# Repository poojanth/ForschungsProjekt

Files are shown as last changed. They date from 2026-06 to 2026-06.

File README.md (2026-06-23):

# ForschungsProjekt
KiCad PCB Design for an Implantable Optical Sensor System for Glioblastoma Cancer Patients

## Overview

This project focused on the design and optimization of a printed circuit board (PCB) for an implantable optical sensor system intended for biomedical research. The system concept is based on fluorescence detection for monitoring possible glioblastoma recurrence after tumor resection.

The implant concept consists of two main parts:

* **Sensor Unit** - responsible for fluorescence excitation and detection.
* **Control Unit** - responsible for power management, signal handling, and system control.

The aim of the project was to improve the electrical design, component selection, PCB layout, compactness, and feasibility of the optical implant system.

---

## My Contribution

* Researched requirements for implantable optical sensor systems
* Compared suitable electronic components for the device
* Investigated power management options for implantable medical devices
* Designed PCB layouts for the sensor unit and control unit using KiCad
* Considered compactness, signal integrity, power/ground planes, and routing rules
* Evaluated an alternative two-step placement approach for improved clinical feasibility

---

## Key Design Considerations

* Fluorescence excitation using UV/blue LEDs
* Fluorescence detection using photodiodes
* Compact PCB layout for implantable use
* Power-efficient component selection
* Separate power and ground planes for improved signal integrity
* MRI compatibility and biocompatibility considerations
* Sensor and control-unit separation for better placement flexibility

---

## Tools Used

* KiCad
* PCB schematic design
* PCB layout design
* Component datasheet analysis
* Literature research

---

## Skills Demonstrated

* PCB design
* Biomedical hardware design
* KiCad workflow
* Component selection
* Power management research
* Sensor system design
* Implantable medical device considerations
* Technical documentation

---

## Repository Structure

```text
.
├── KiCad_Project/
│   ├── project_file.kicad_pro
│   ├── schematic.kicad_sch
│   └── pcb_layout.kicad_pcb
│
├── Docs/
│   ├── schematic.pdf
│   ├── pcb_layout_images/
│   └── 3d_pcb_views/
│
├── README.md
└── .gitignore
```

---

## Project Status

This project represents a research and design-stage PCB development work. The PCB layout and component selection were completed as part of the research project. Experimental validation and hardware testing were identified as future work.

---

## Confidentiality Note

This repository contains only a non-confidential project overview and selected design documentation. Sensitive institutional material, unpublished restricted details, and confidential research data are not included.

---

## Author

**Poojan Thakar**
M.Sc. Medical Systems Engineering
Otto von Guericke University Magdeburg

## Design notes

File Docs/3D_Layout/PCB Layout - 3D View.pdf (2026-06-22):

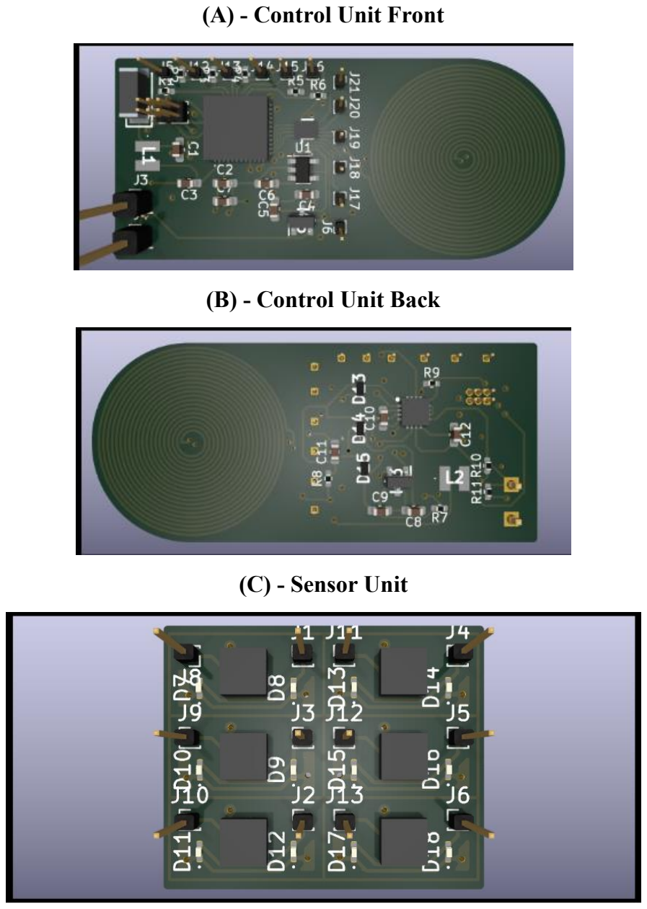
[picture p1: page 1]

(A) - Control Unit Front
(B) - Control Unit Back
(C) - Sensor Unit

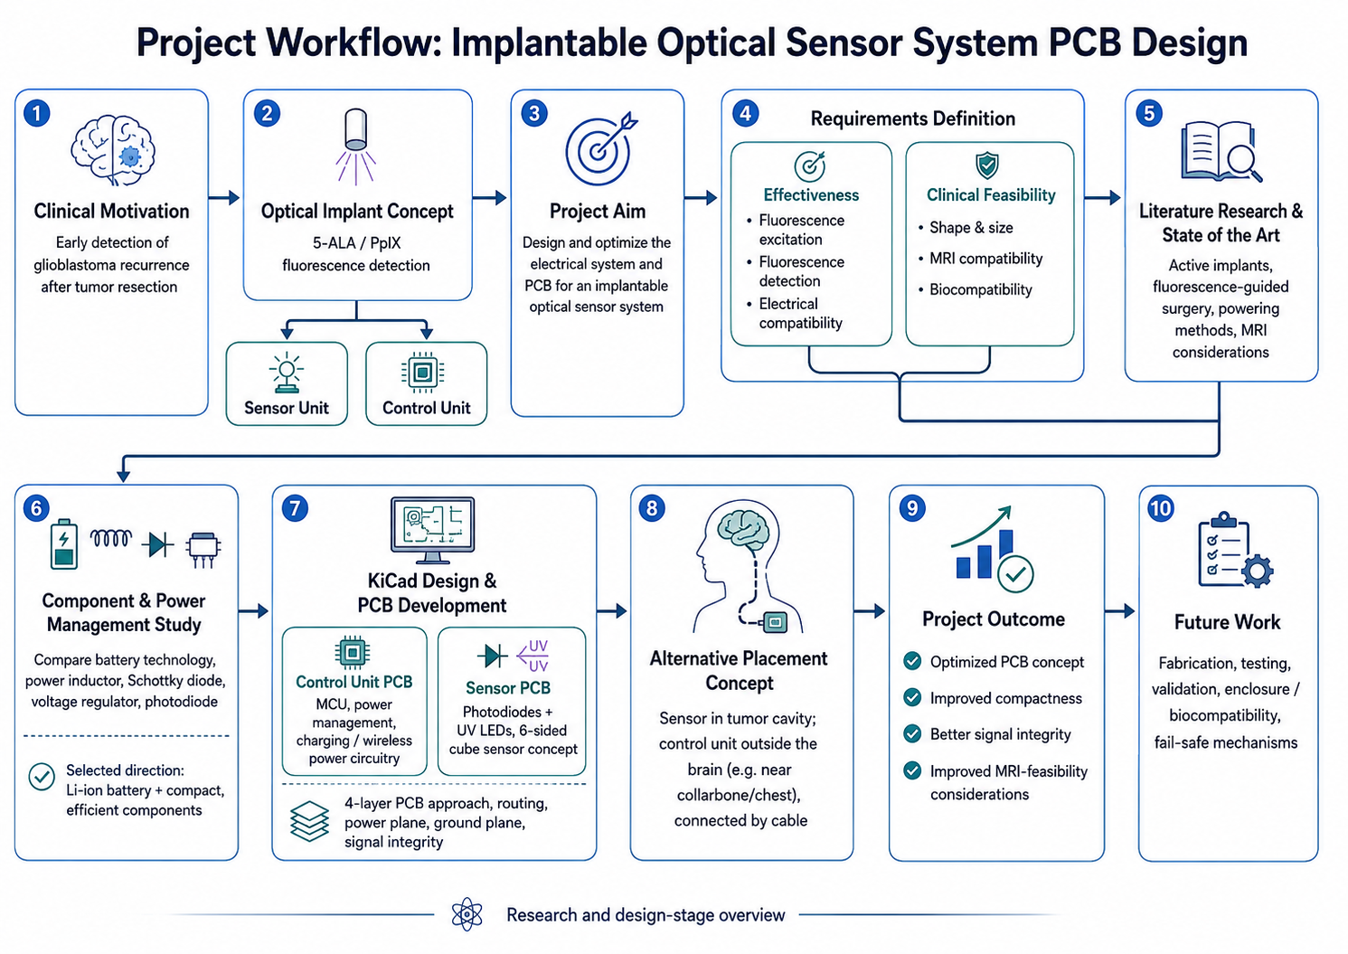
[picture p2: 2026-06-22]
Docs/Workflow/Research Project - Workflow.png

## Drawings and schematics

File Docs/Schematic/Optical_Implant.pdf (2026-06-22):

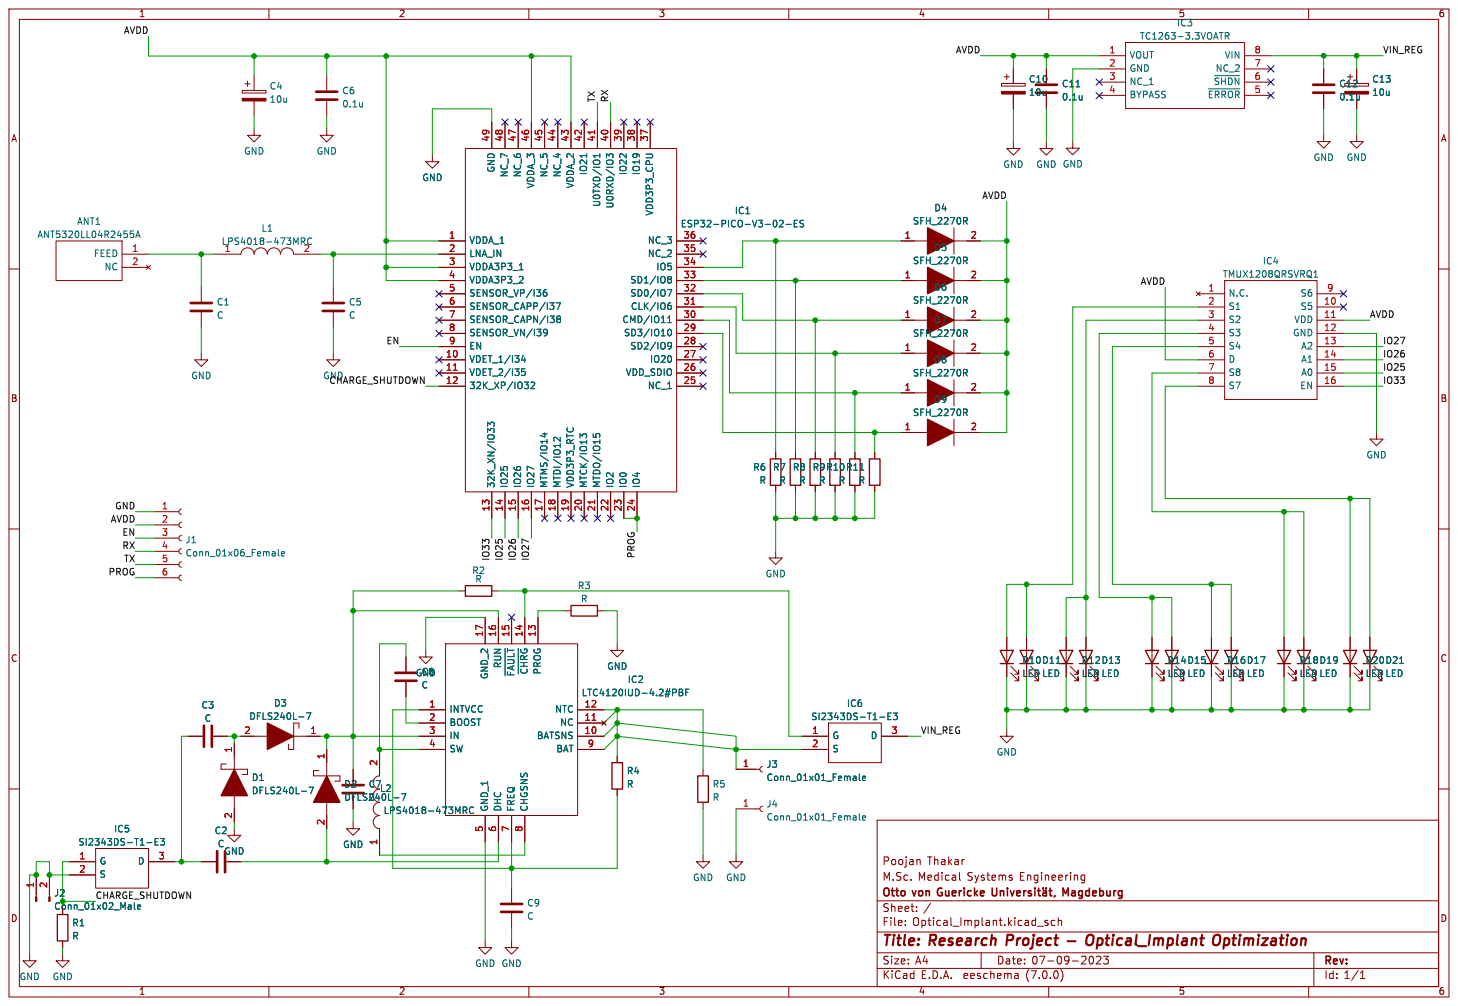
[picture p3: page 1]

Id: 1/1 Title: Research Project - Optical_Implant Optimization

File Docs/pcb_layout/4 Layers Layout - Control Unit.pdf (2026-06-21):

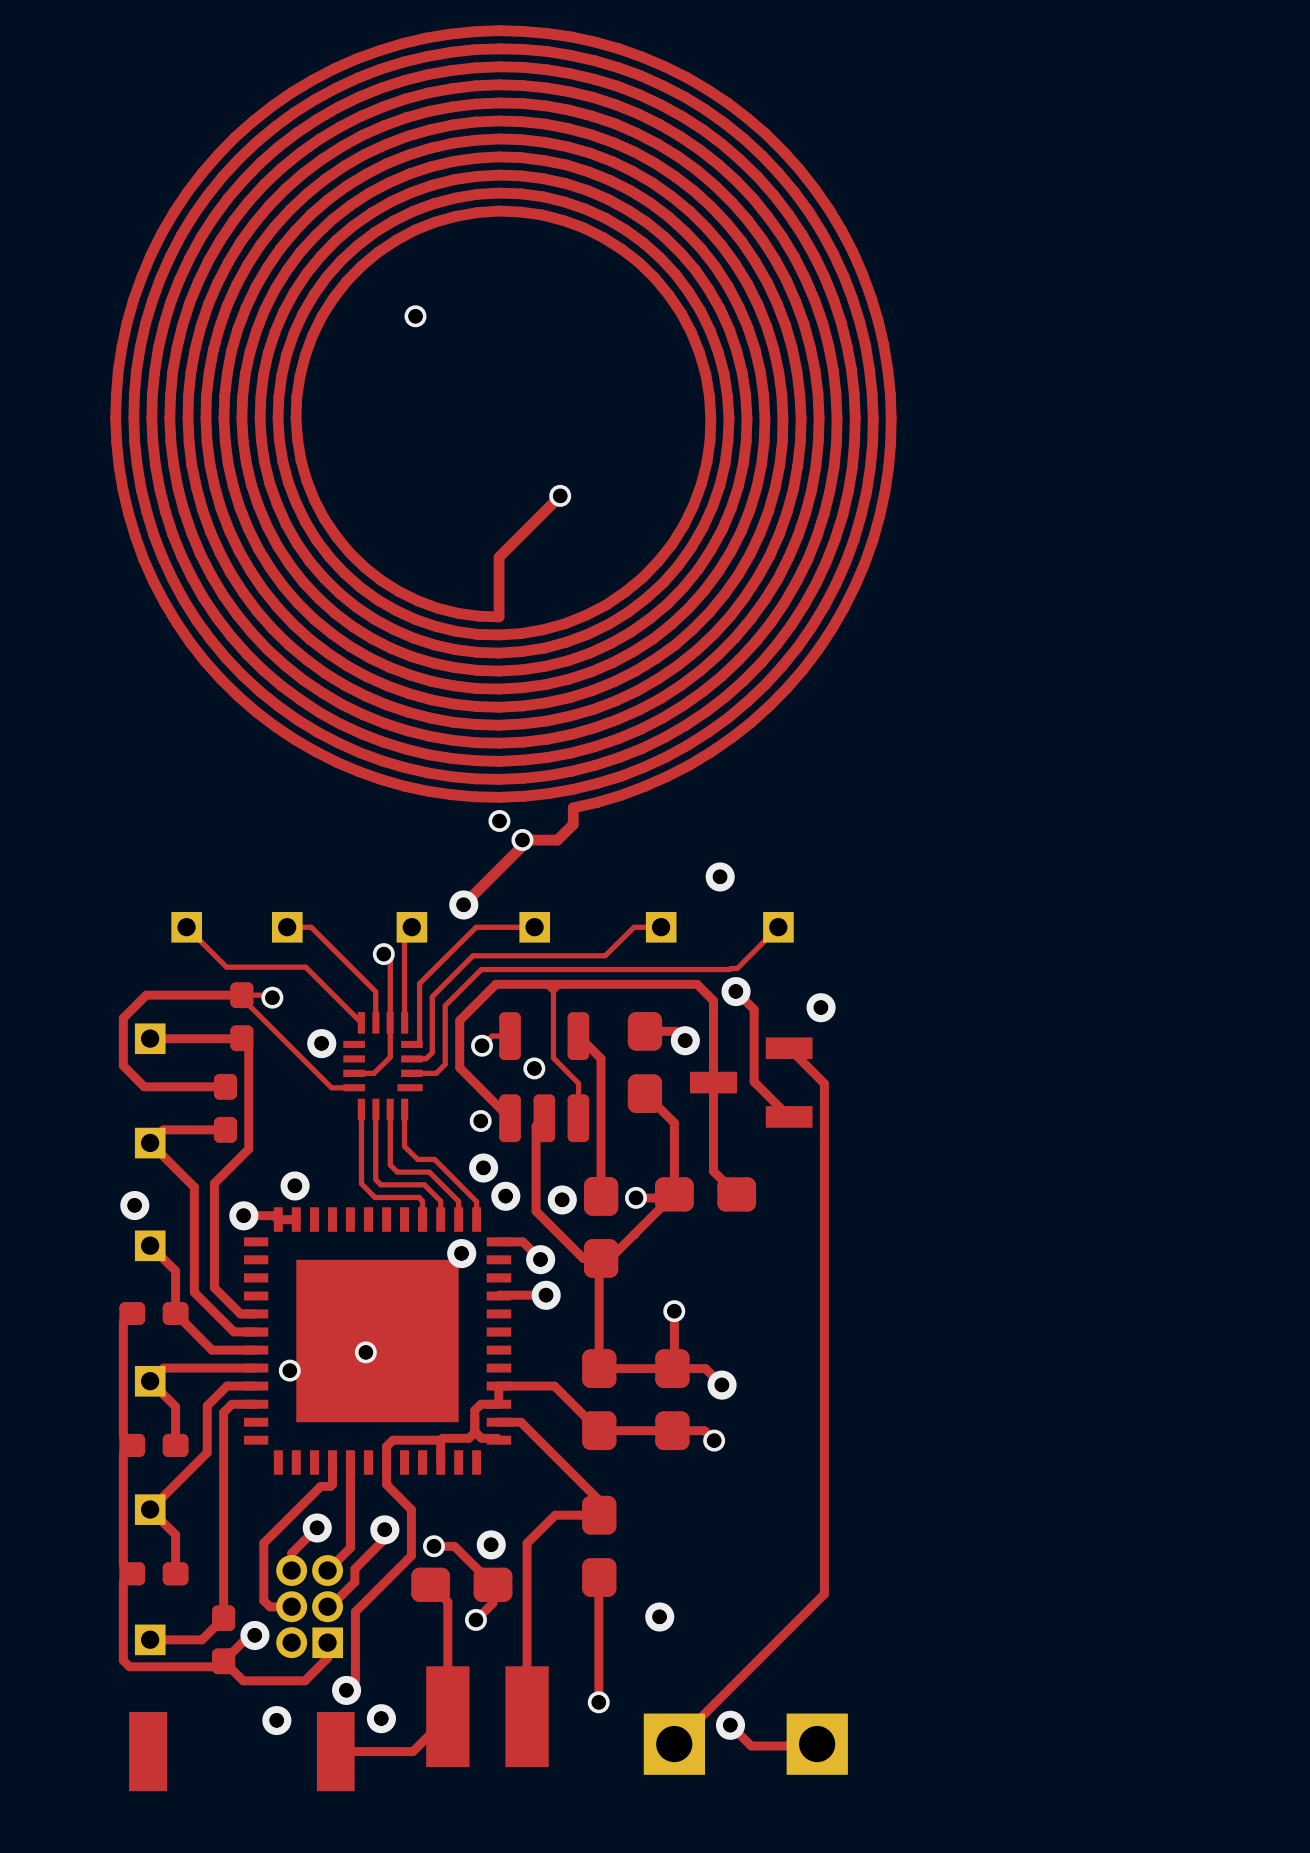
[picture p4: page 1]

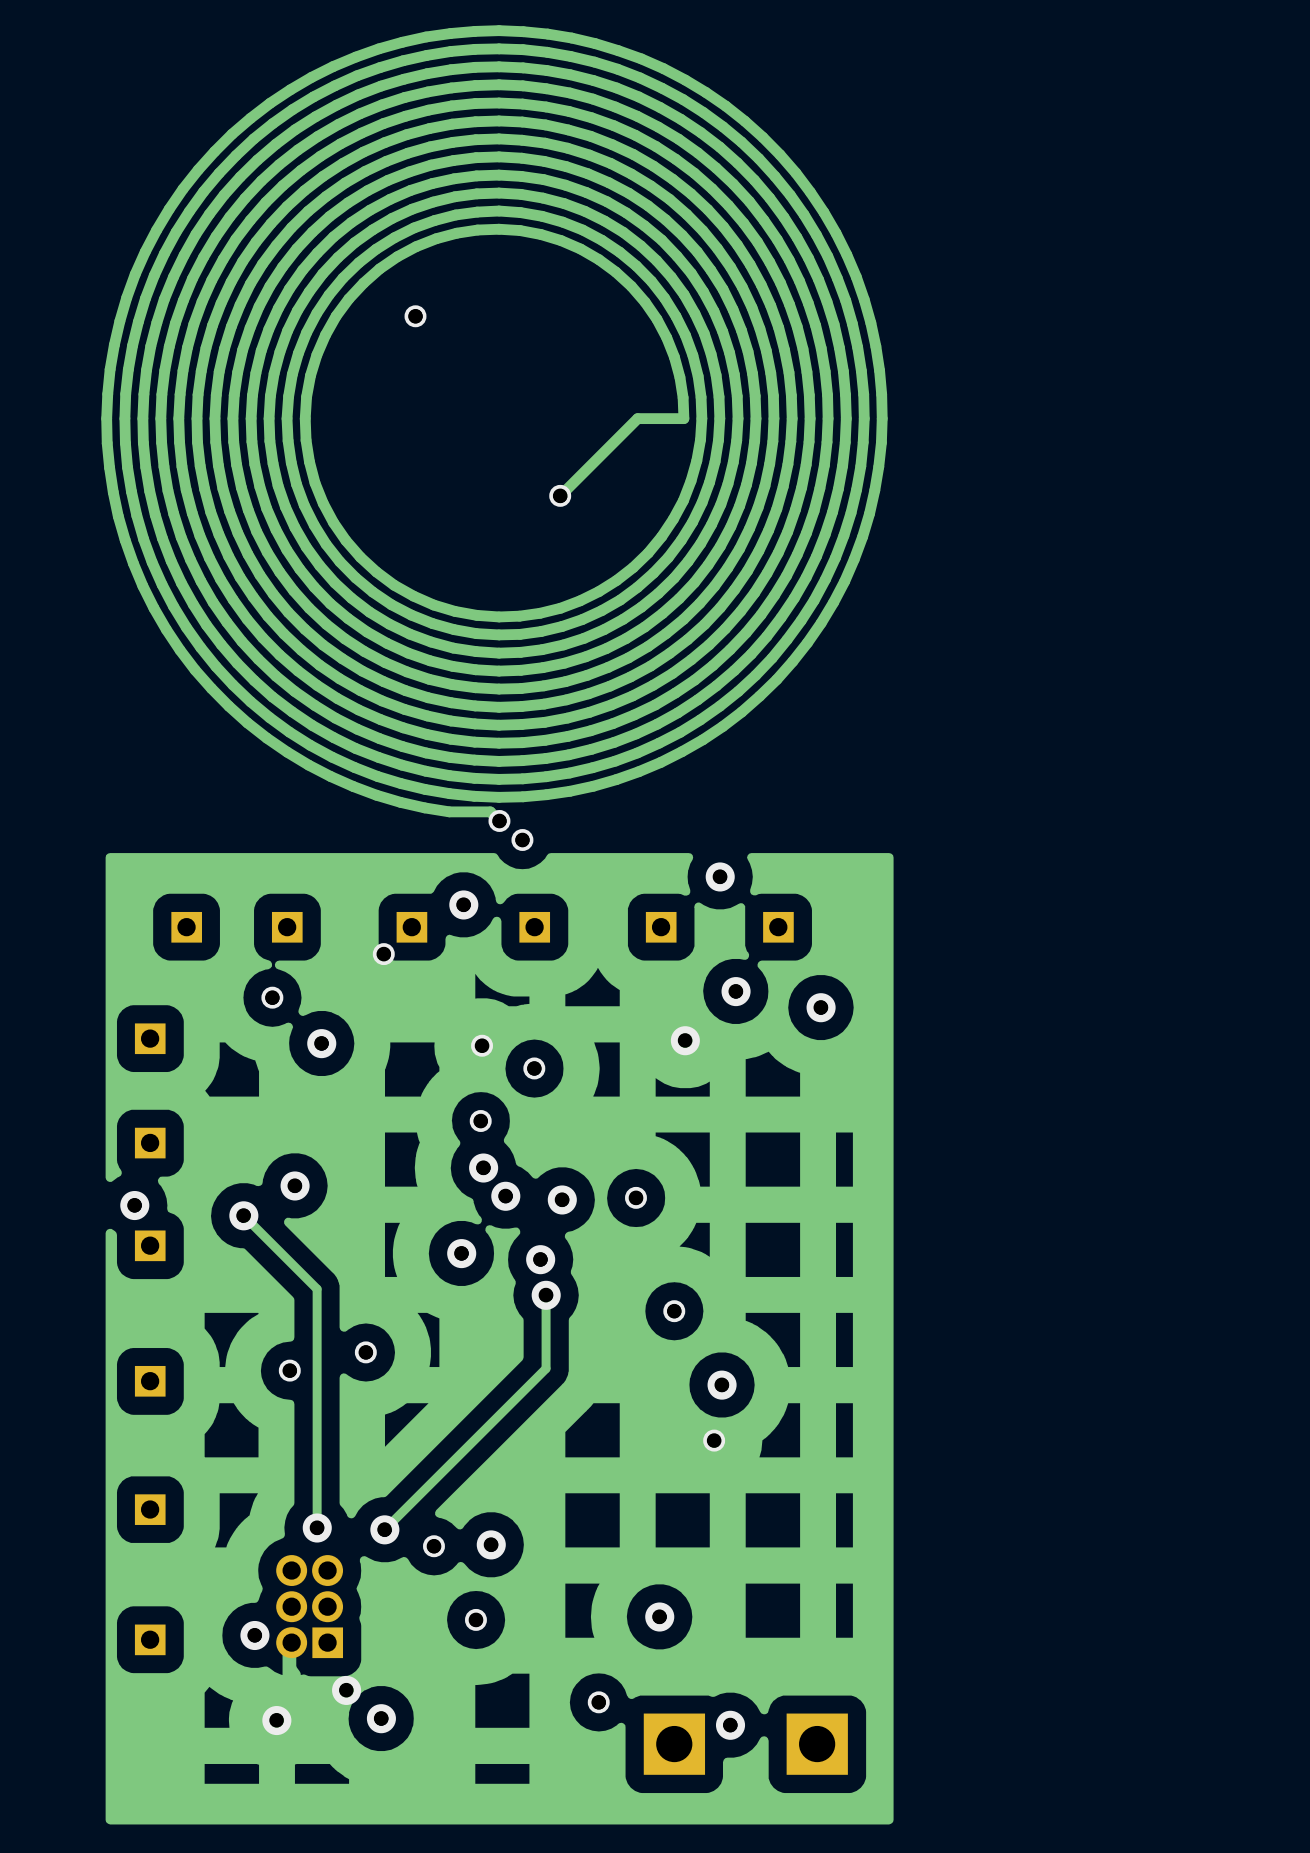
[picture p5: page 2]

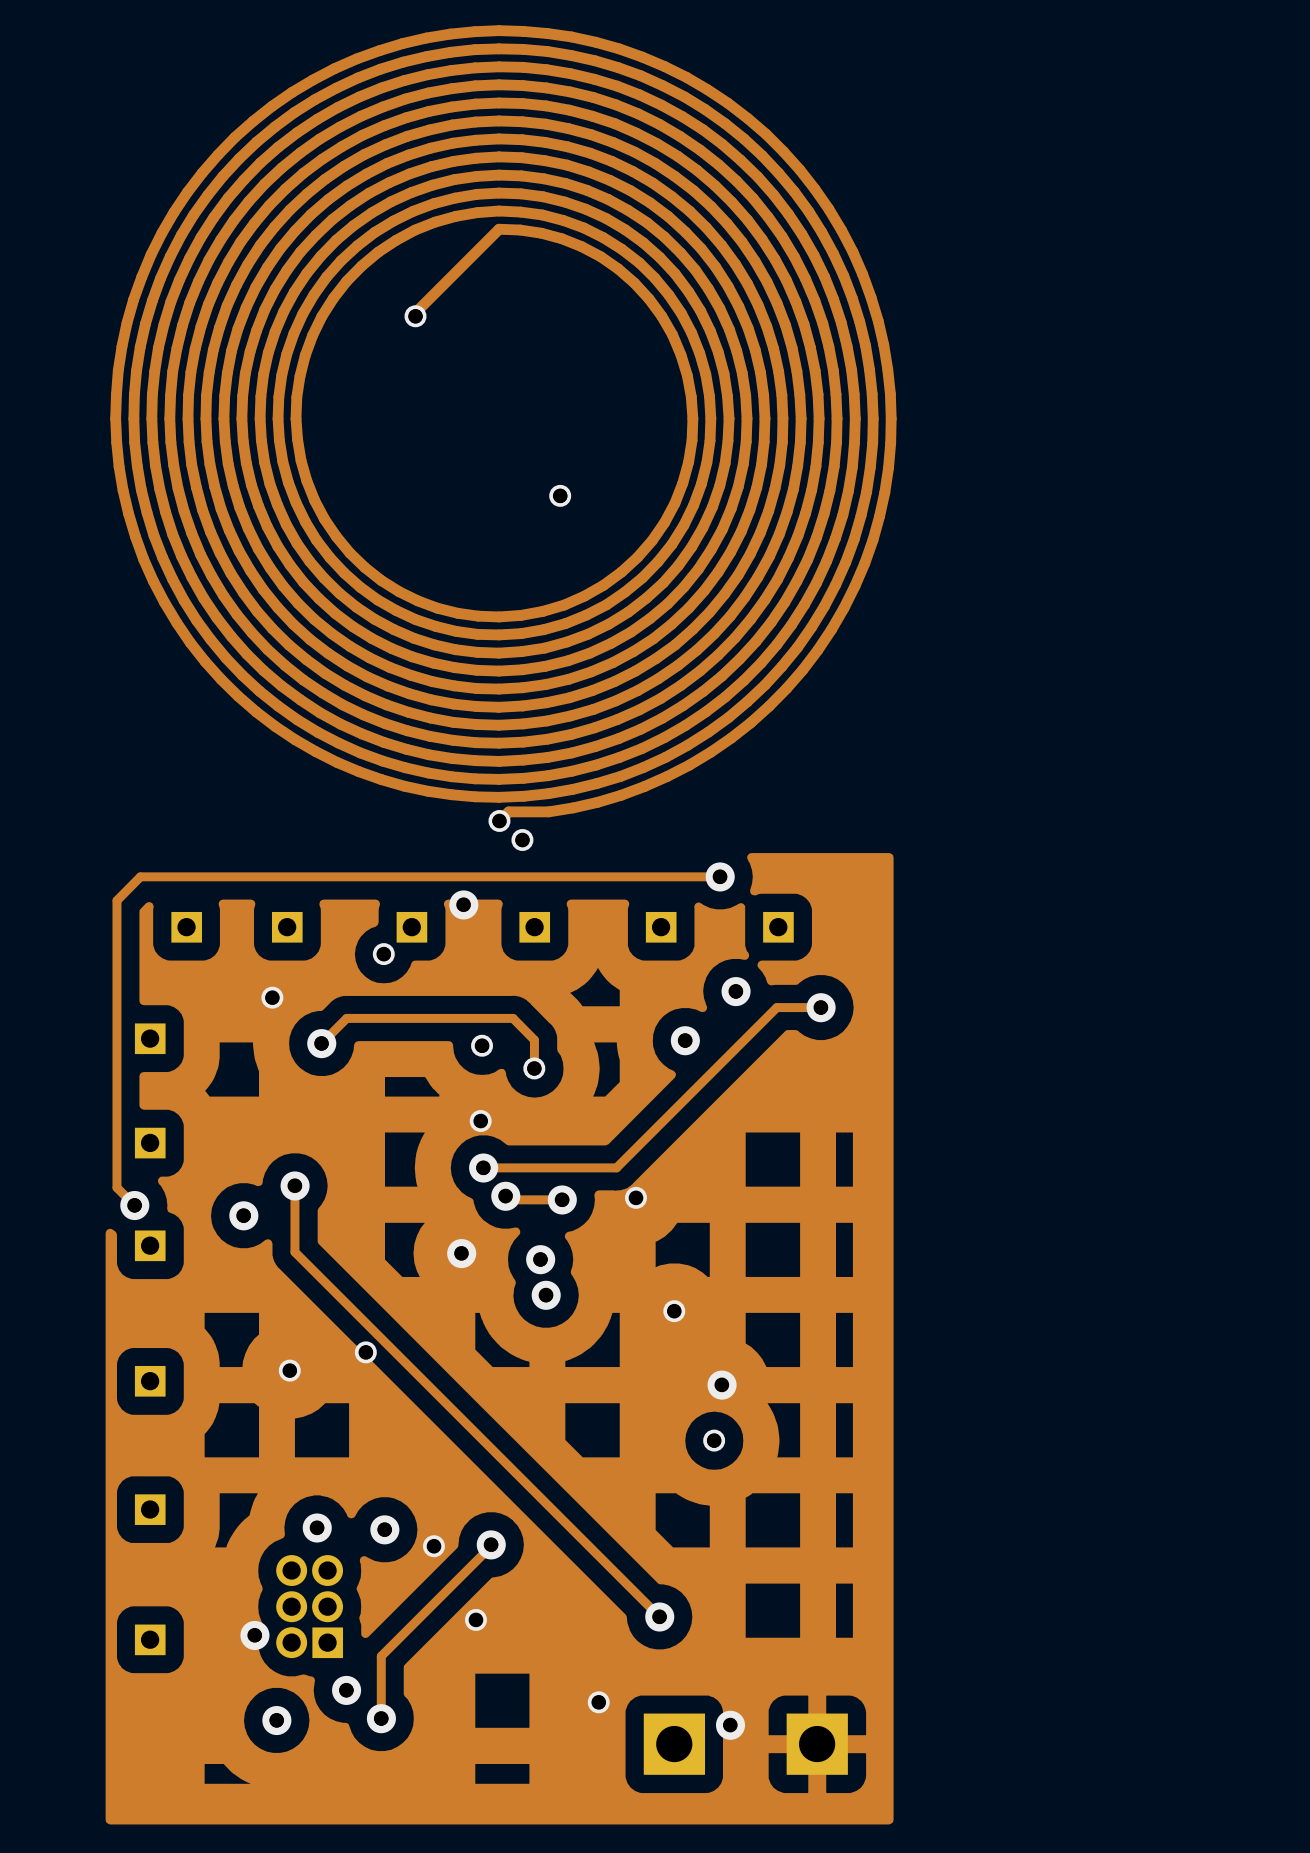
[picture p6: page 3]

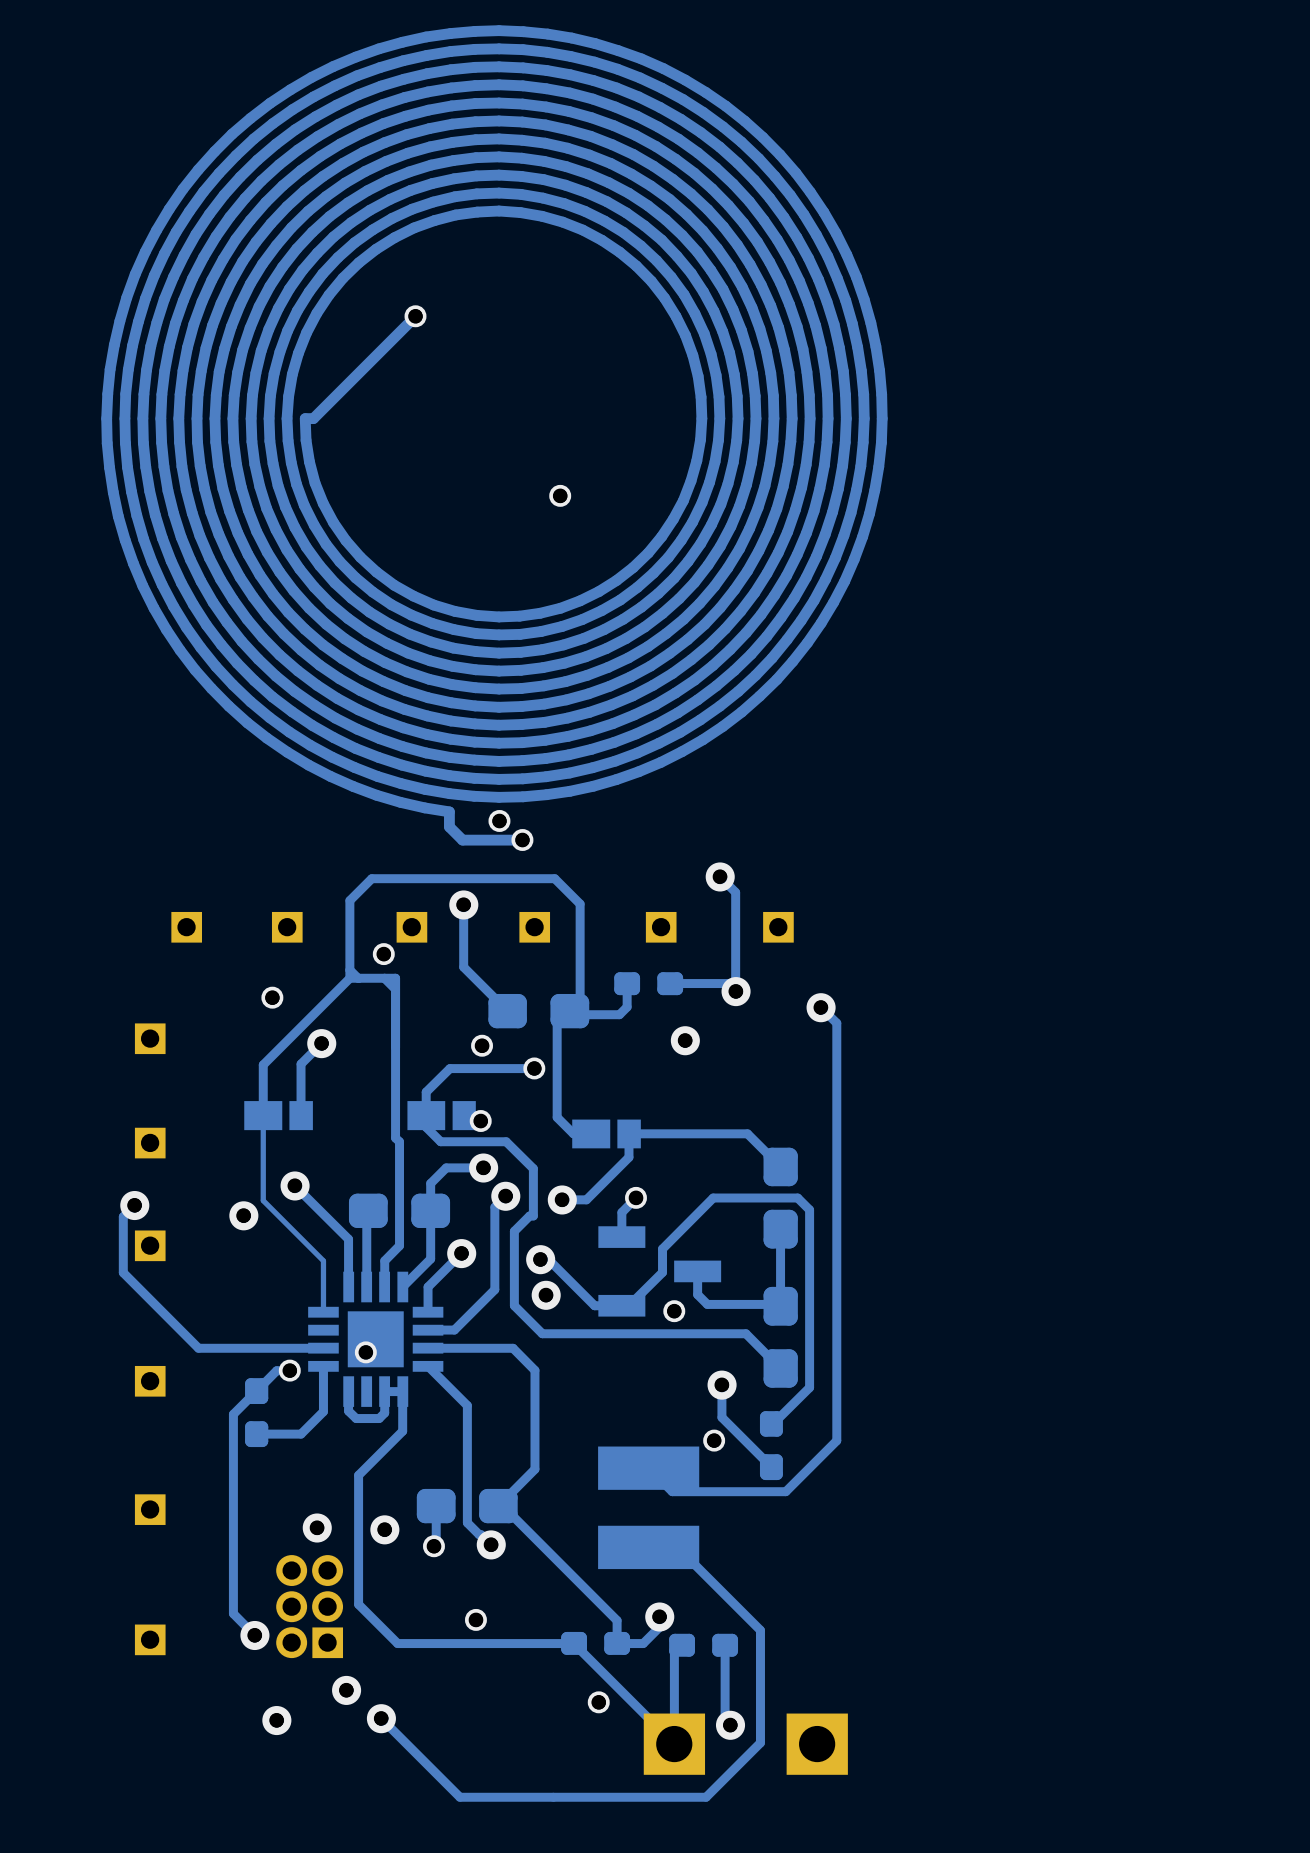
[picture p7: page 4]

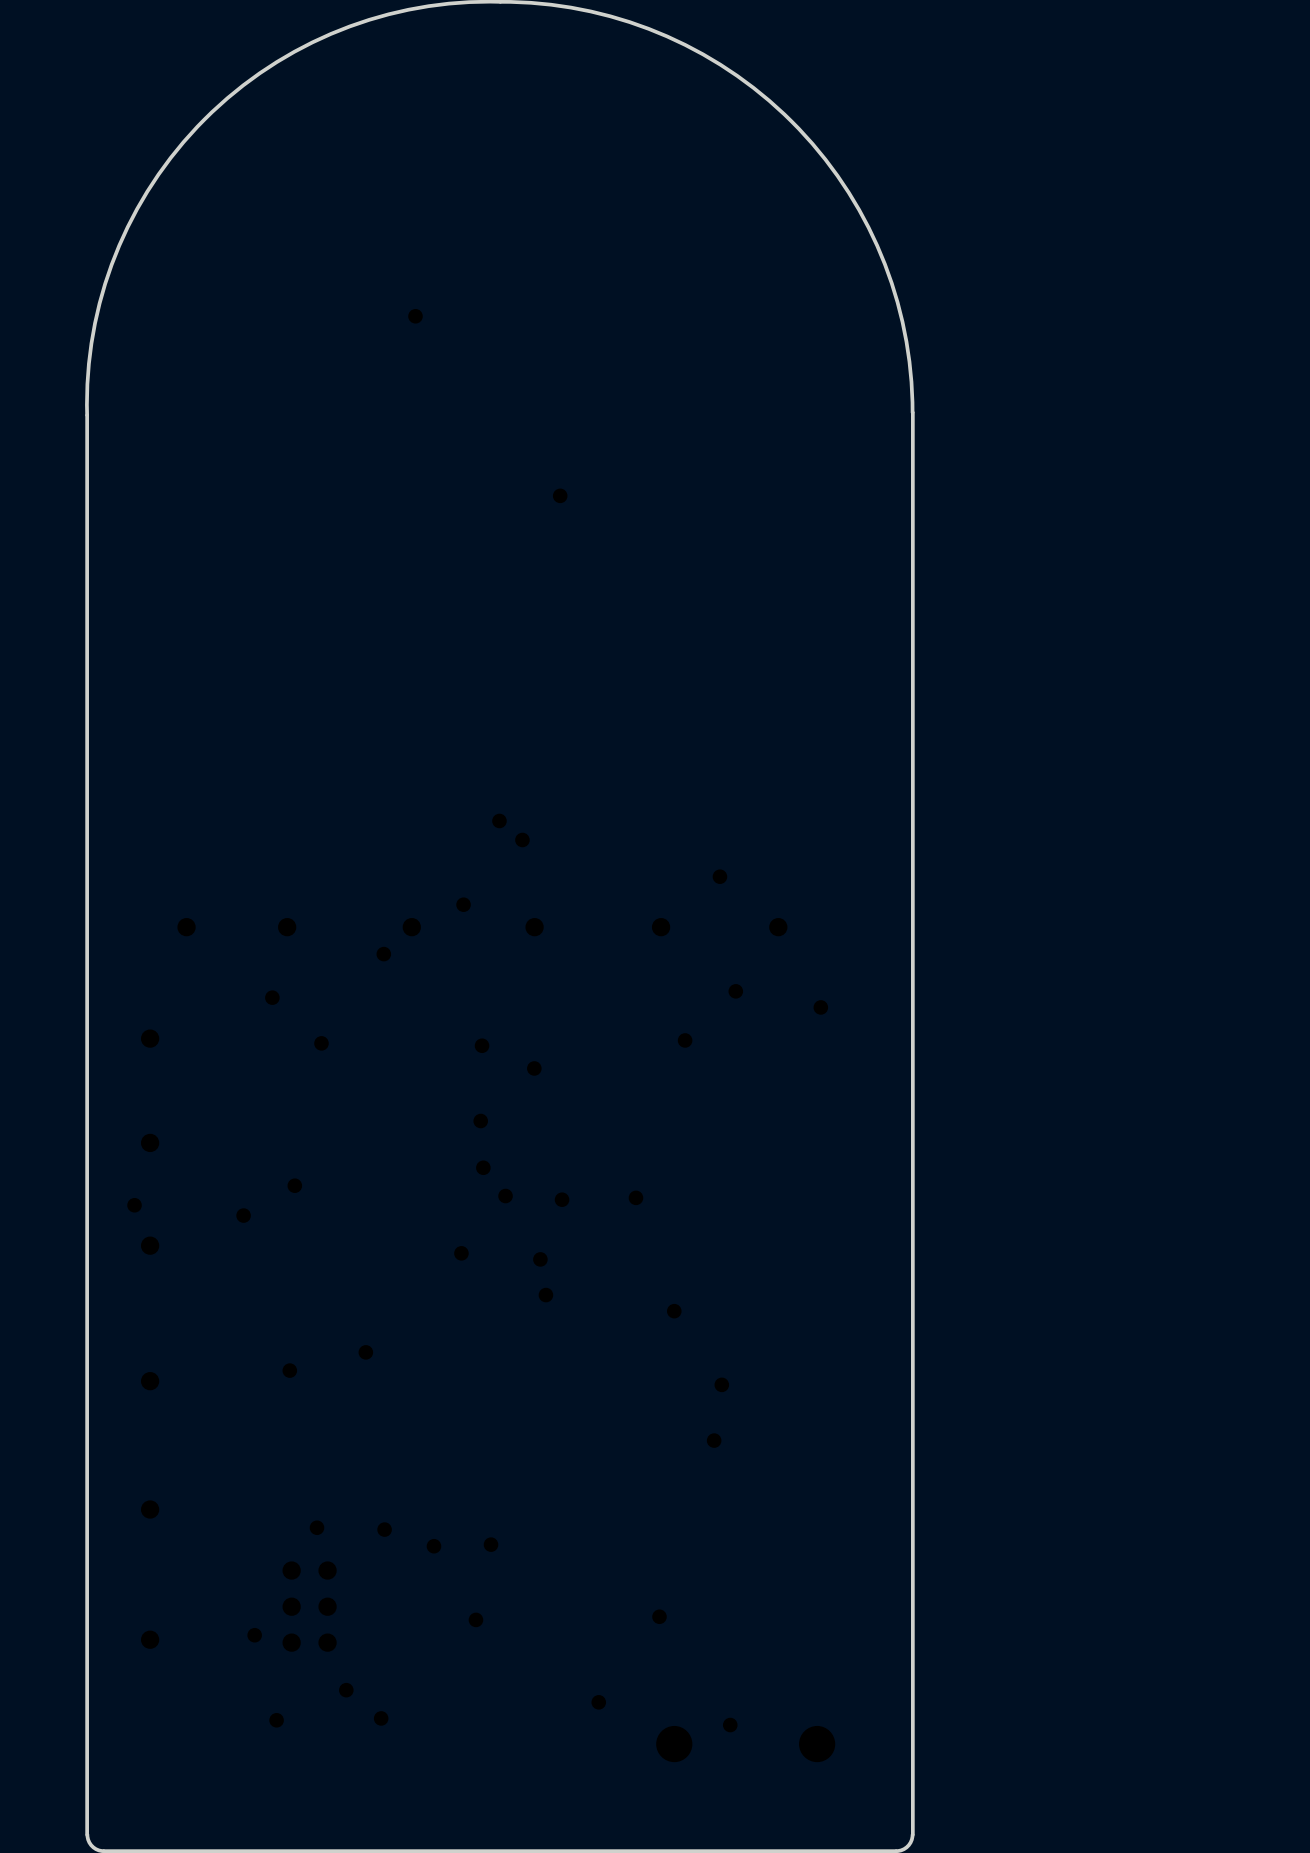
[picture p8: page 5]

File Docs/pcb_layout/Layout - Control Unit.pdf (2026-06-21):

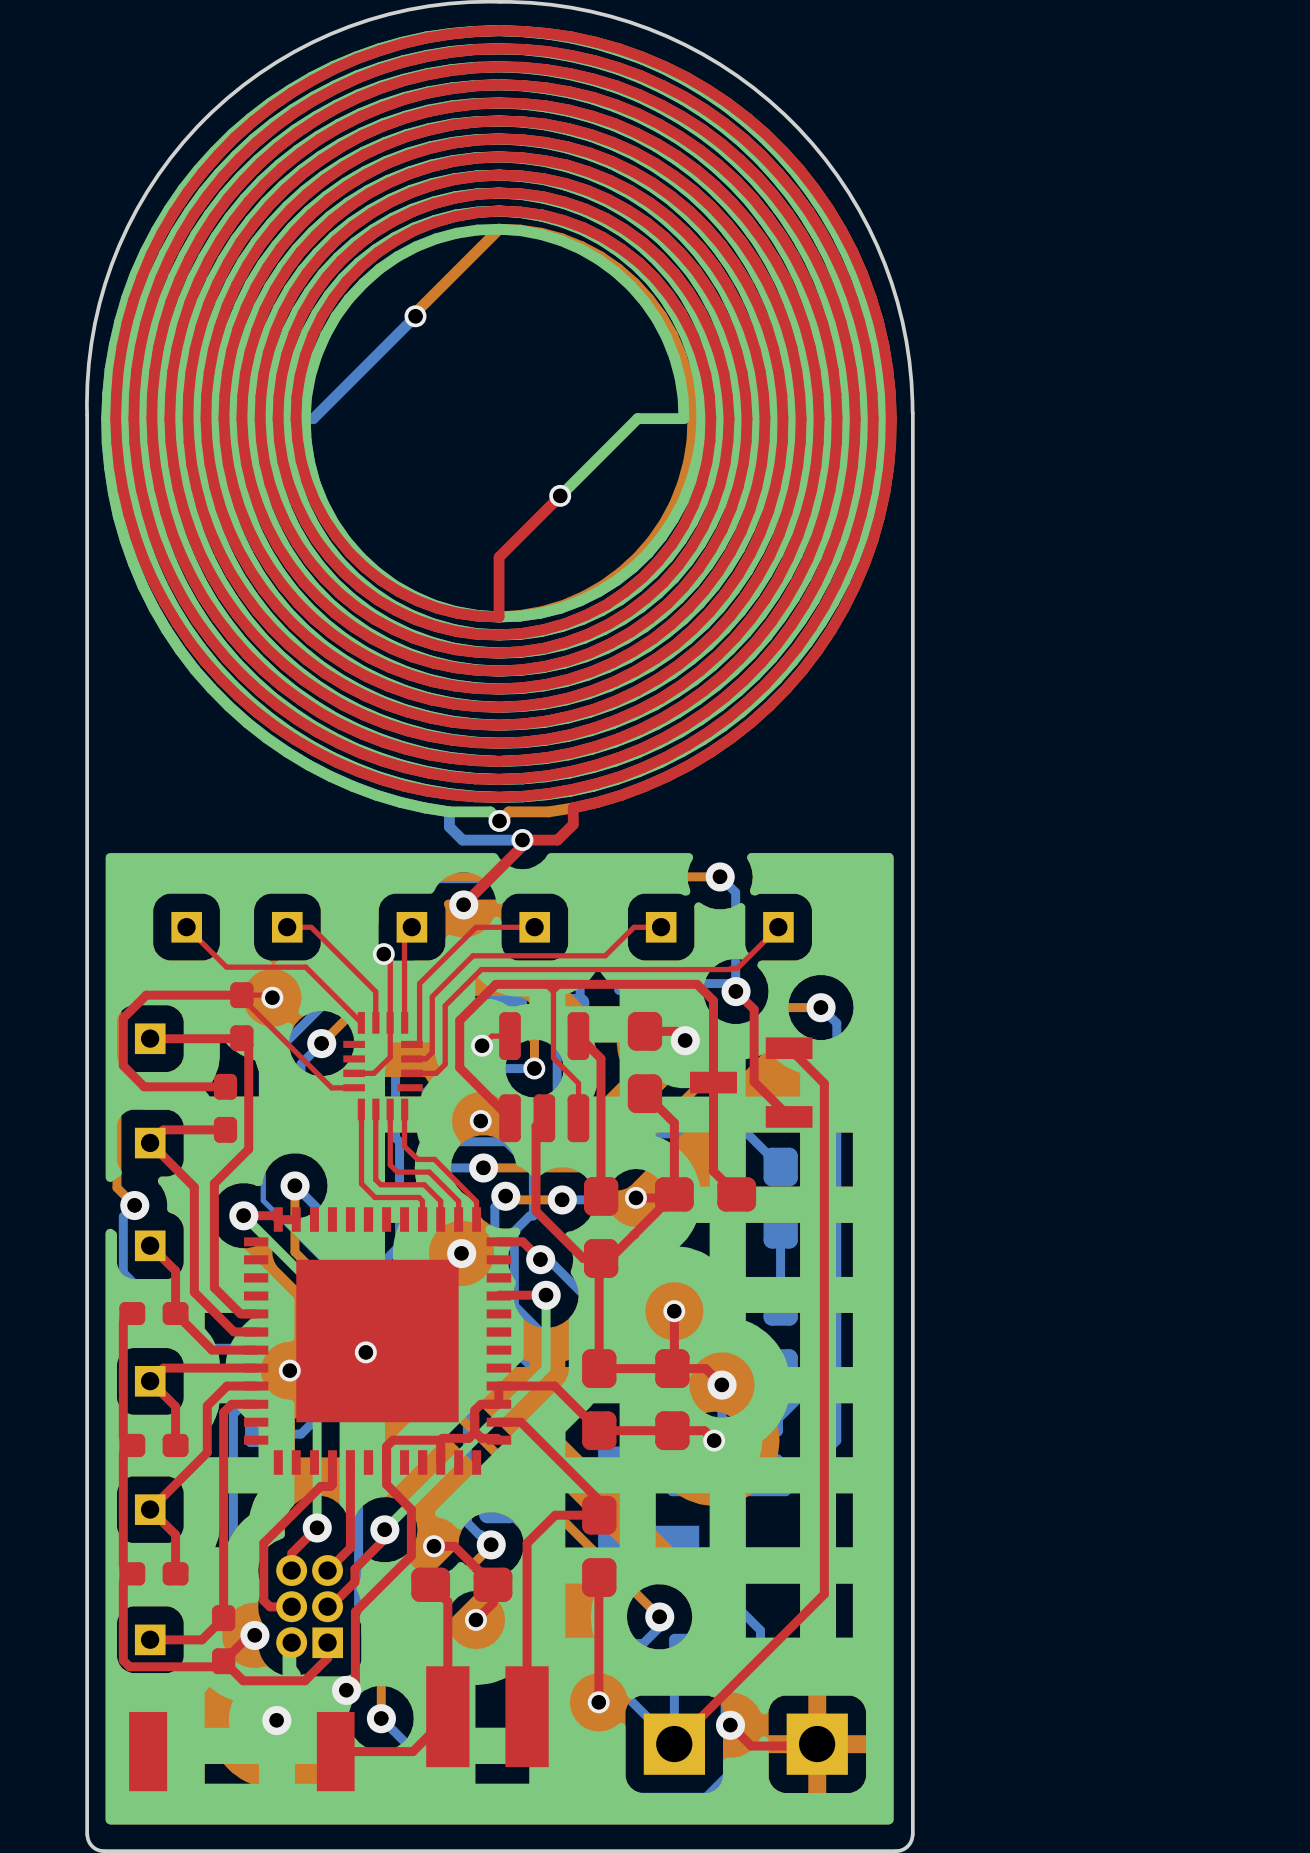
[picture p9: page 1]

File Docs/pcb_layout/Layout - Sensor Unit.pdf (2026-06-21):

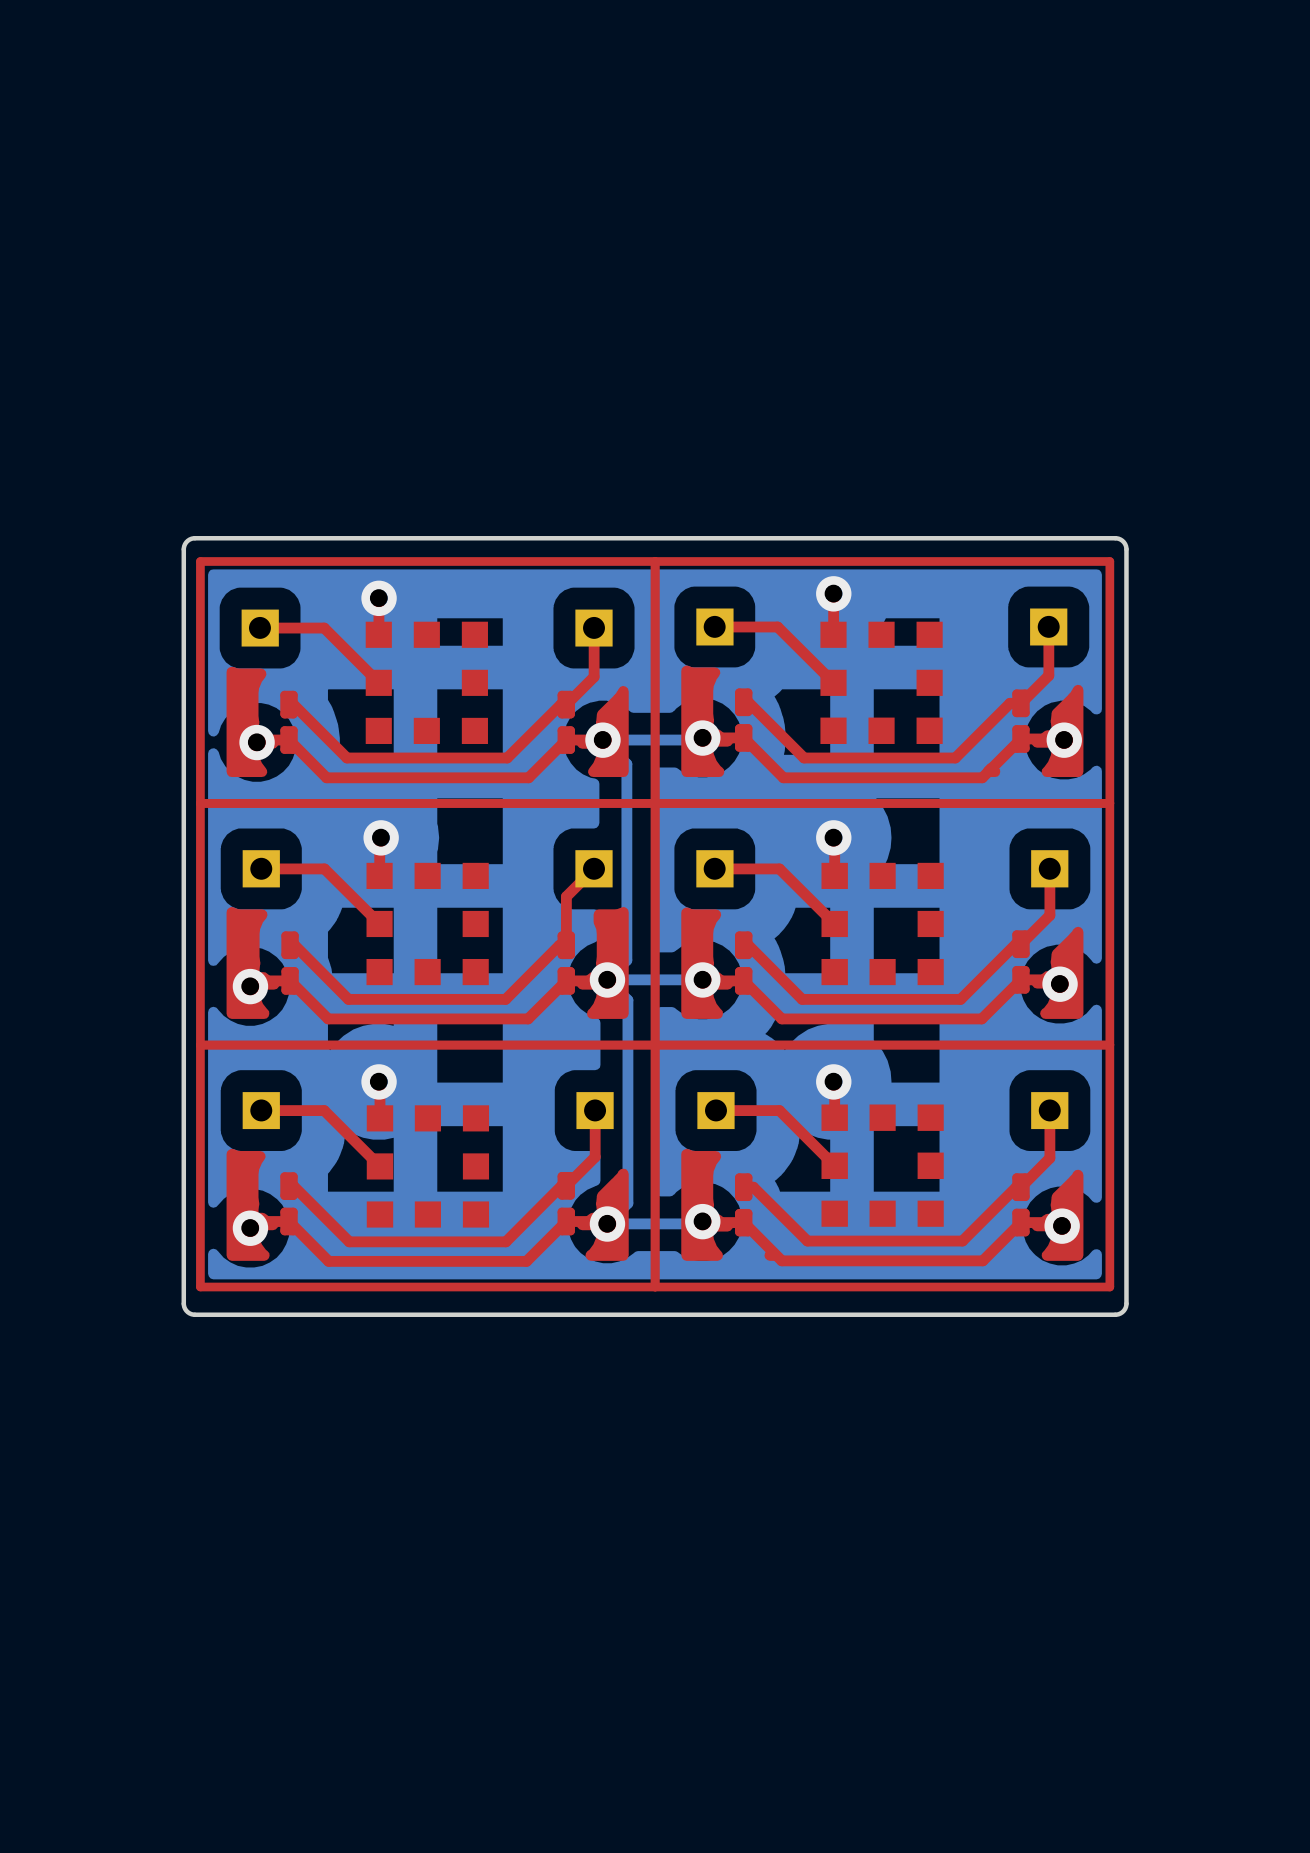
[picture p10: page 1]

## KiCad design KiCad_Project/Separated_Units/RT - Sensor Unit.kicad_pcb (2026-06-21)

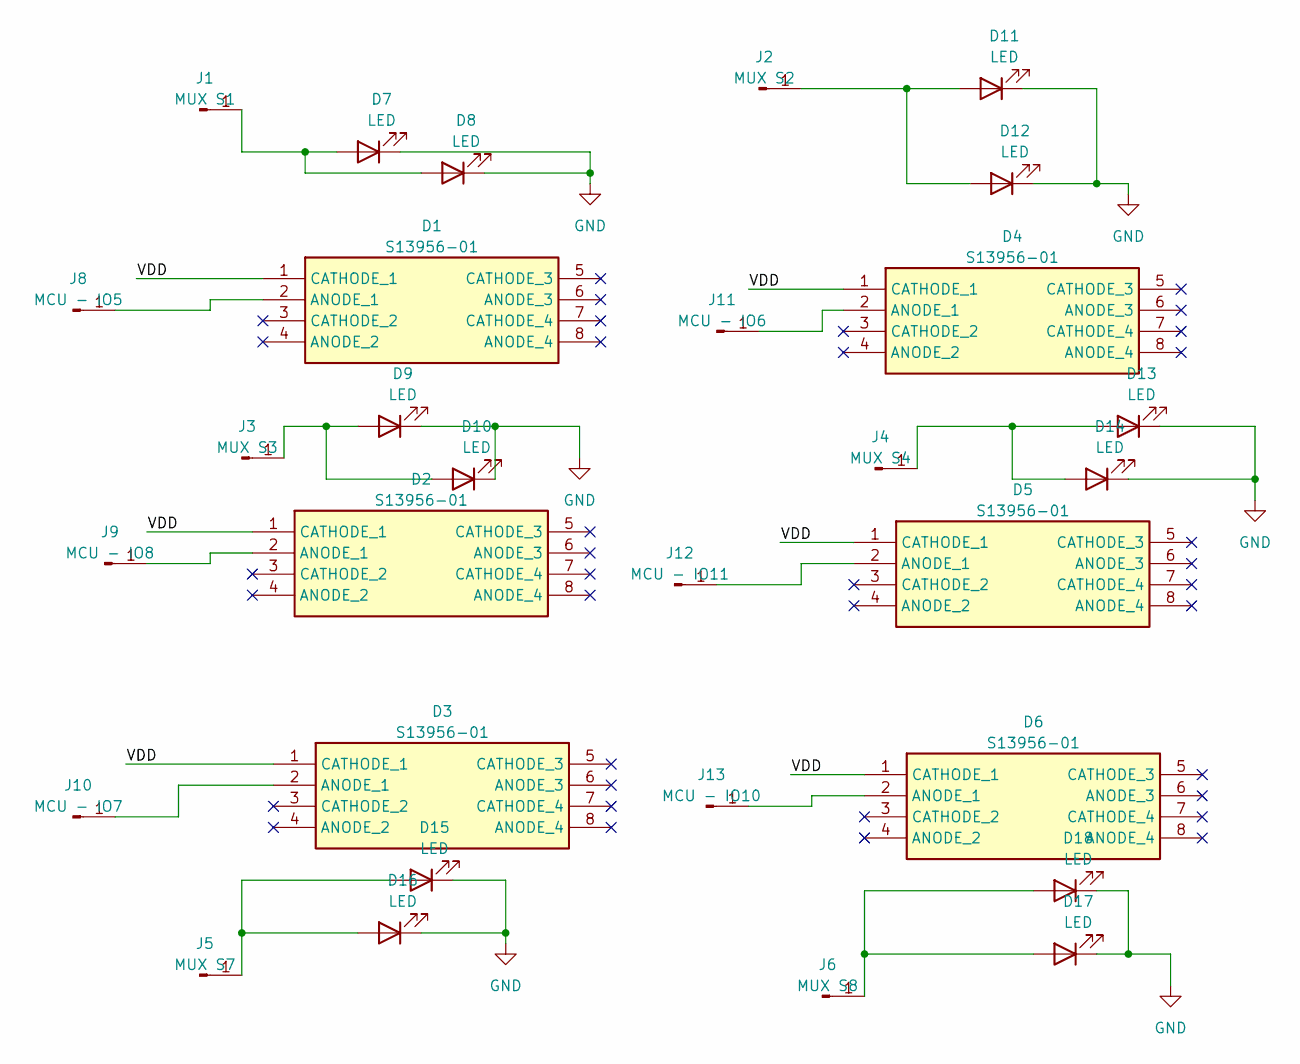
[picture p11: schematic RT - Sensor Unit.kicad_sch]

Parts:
D1, D2, D3, D4, D5, D6: S13956-01; S1395601; Manufacturer_Part_Number S13956-01
D7, D8, D9, D10, D11, D12, D13, D14, D15, D16, D17, D18: LED; LED_0201_0603Metric_Pad0.64x0.40mm_HandSolder
J1: MUX S1; PinHeader_1x01_P1.00mm_Vertical
J2: MUX S2; PinHeader_1x01_P1.00mm_Vertical
J3: MUX S3; PinHeader_1x01_P1.00mm_Vertical
J4: MUX S4; PinHeader_1x01_P1.00mm_Vertical
J5: MUX S7; PinHeader_1x01_P1.00mm_Vertical
J6: MUX S8; PinHeader_1x01_P1.00mm_Vertical
J8: MCU - IO5; PinHeader_1x01_P1.00mm_Vertical
J9: MCU - IO8; PinHeader_1x01_P1.00mm_Vertical
J10: MCU - IO7; PinHeader_1x01_P1.00mm_Vertical
J11: MCU - IO6; PinHeader_1x01_P1.00mm_Vertical
J12: MCU - IO11; PinHeader_1x01_P1.00mm_Vertical
J13: MCU - IO10; PinHeader_1x01_P1.00mm_Vertical

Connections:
/VDD: D1.1 (CATHODE_1), D2.1 (CATHODE_1), D3.1 (CATHODE_1), D4.1 (CATHODE_1), D5.1 (CATHODE_1), D6.1 (CATHODE_1)
GND: D7.1 (K), D8.1 (K), D9.1 (K), D10.1 (K), D11.1 (K), D12.1 (K), D13.1 (K), D14.1 (K), D15.1 (K), D16.1 (K), D17.1 (K), D18.1 (K)
unnamed: D1.2 (ANODE_1), J8.1
unnamed: D2.2 (ANODE_1), J9.1
unnamed: D3.2 (ANODE_1), J10.1
unnamed: D4.2 (ANODE_1), J11.1
unnamed: D5.2 (ANODE_1), J12.1
unnamed: D6.2 (ANODE_1), J13.1
unnamed: D7.2 (A), D8.2 (A), J1.1
unnamed: D9.2 (A), D10.2 (A), J3.1
unnamed: D11.2 (A), D12.2 (A), J2.1
unnamed: D13.2 (A), D14.2 (A), J4.1
unnamed: D15.2 (A), D16.2 (A), J5.1
unnamed: D17.2 (A), D18.2 (A), J6.1

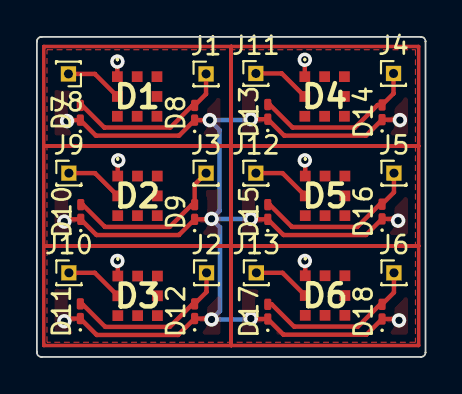
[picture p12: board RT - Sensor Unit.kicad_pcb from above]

Board: 2 copper layers, 21.6 x 17.8 mm, 30 parts (0 on the bottom side), 14 nets.

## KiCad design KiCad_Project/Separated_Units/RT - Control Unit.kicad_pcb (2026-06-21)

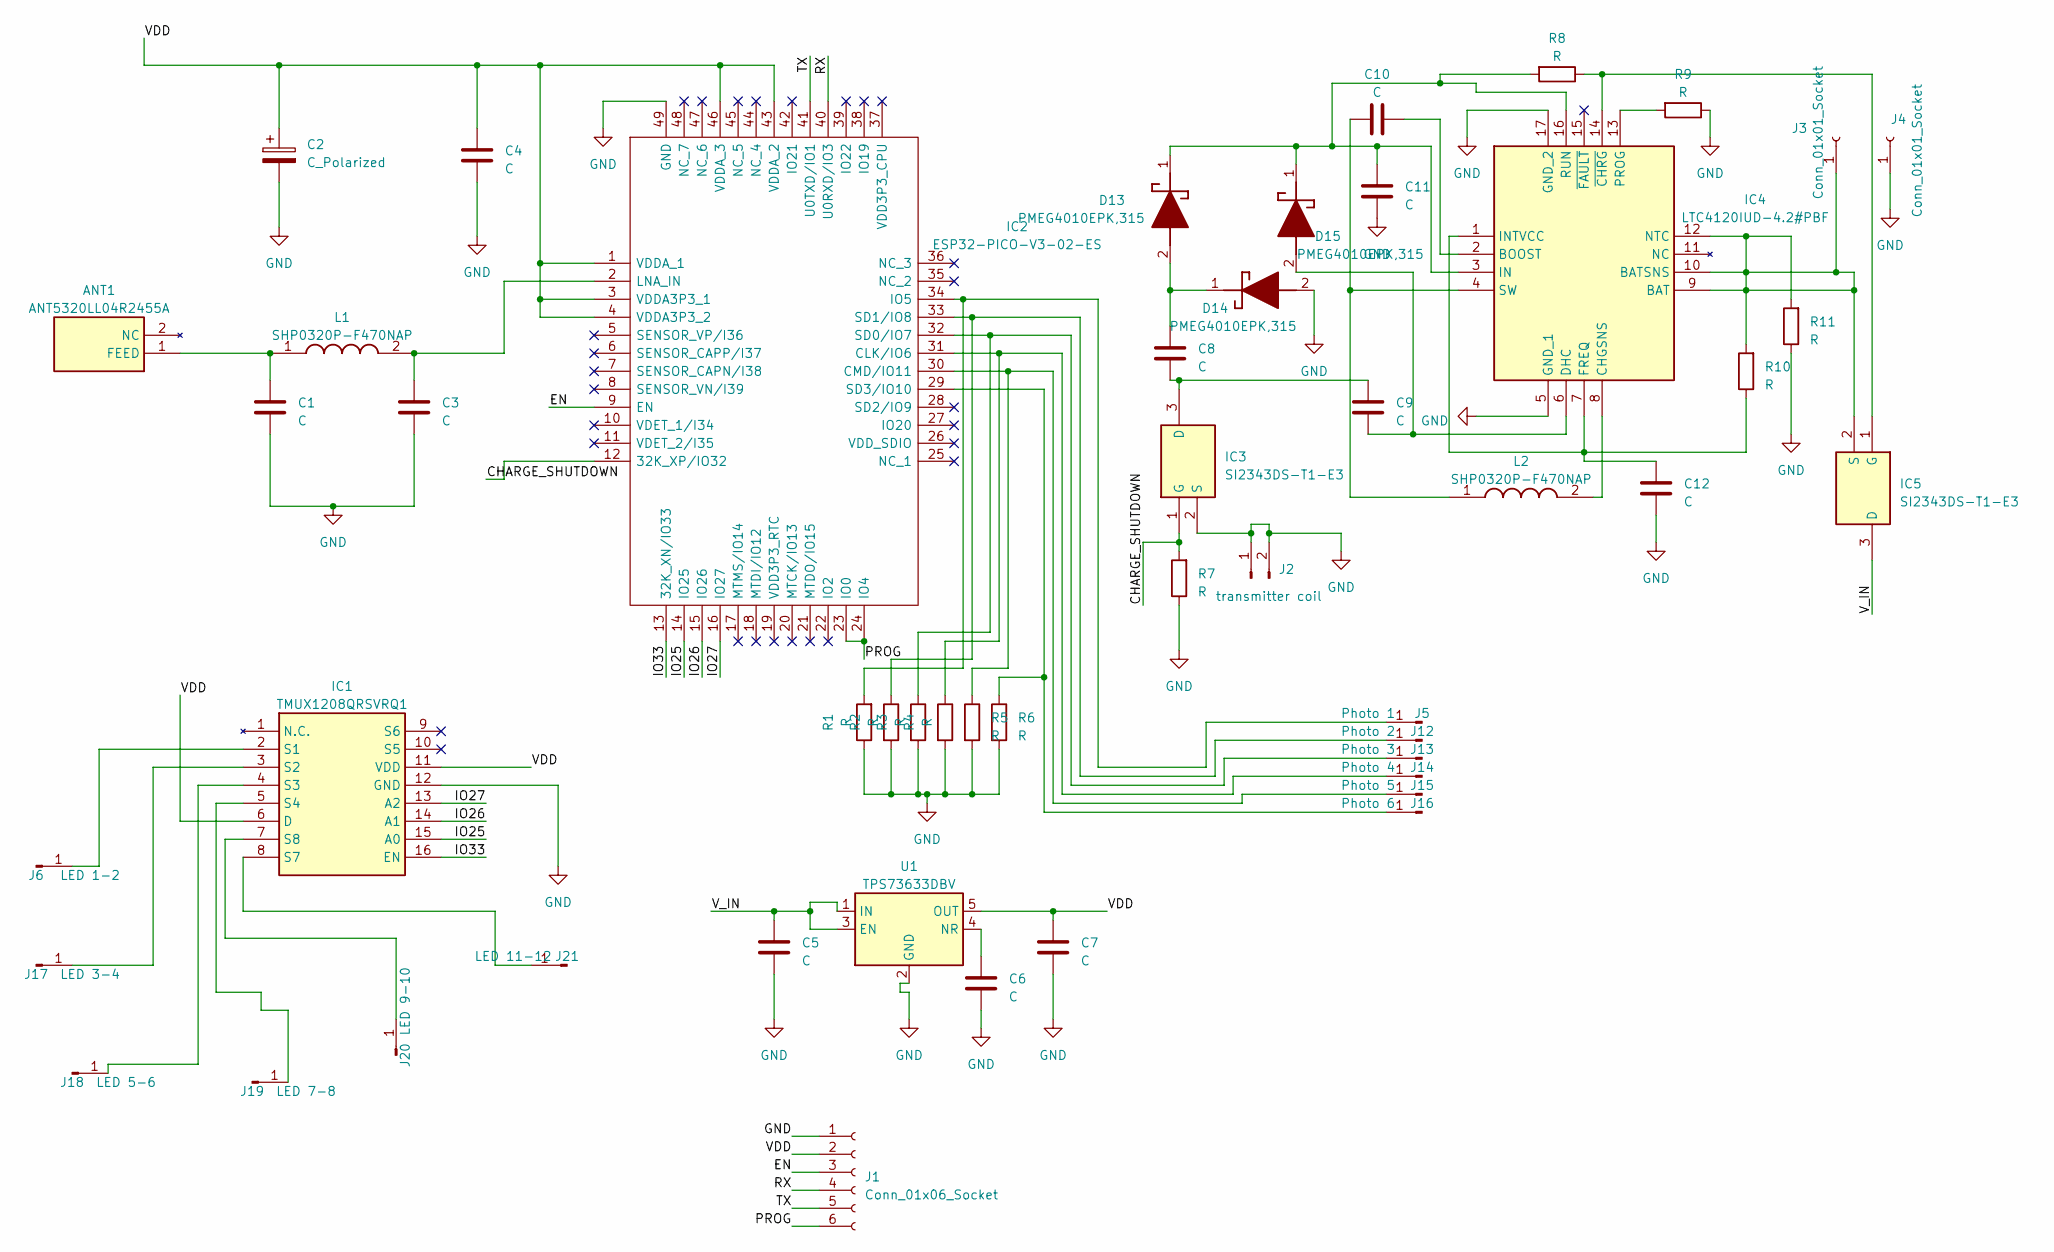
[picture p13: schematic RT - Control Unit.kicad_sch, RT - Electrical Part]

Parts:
ANT1: ANT5320LL04R2455A; ANTC5320X170N; Manufacturer_Part_Number ANT5320LL04R2455A; Mouser Part Number 603-ANT5320LL04R2455
C1, C3, C4, C5, C6, C7, C8, C9, C10, C11, C12: C; C_0603_1608Metric_Pad1.08x0.95mm_HandSolder
C2: C_Polarized; C_0603_1608Metric_Pad1.08x0.95mm_HandSolder
D13, D14, D15: PMEG4010EPK,315; PMEG4010EPK315; Manufacturer_Part_Number PMEG4010EPK,315; Mouser Part Number 771-PMEG4010EPK,315
IC1: TMUX1208QRSVRQ1; Manufacturer_Part_Number TMUX1208QRSVRQ1; Mouser Part Number 595-TMUX1208QRSVRQ1
IC2: ESP32-PICO-V3-02-ES; ESP32PICOV302ES; Manufacturer_Part_Number ESP32-PICO-V3-02-ES
IC3, IC5: SI2343DS-T1-E3; SOT95P237X112-3N; Manufacturer_Part_Number SI2343DS-T1-E3; Mouser Part Number 781-SI2343DS-T1-E3
IC4: LTC4120IUD-4.2#PBF; QFN50P300X300X80-17N-D; Manufacturer_Part_Number LTC4120IUD-4.2#PBF; Mouser Part Number 584-C4120IUD-4.2PBF
J1: Conn_01x06_Socket; PinHeader_2x03_P1.00mm_Vertical
J2: transmitter coil; PinHeader_1x02_P1.00mm_Vertical
J3, J4: Conn_01x01_Socket; PinHeader_1x01_P2.54mm_Vertical
J5: Photo 1; PinHeader_1x01_P1.00mm_Vertical
J6: LED 1-2; PinHeader_1x01_P1.00mm_Vertical
J12: Photo 2; PinHeader_1x01_P1.00mm_Vertical
J13: Photo 3; PinHeader_1x01_P1.00mm_Vertical
J14: Photo 4; PinHeader_1x01_P1.00mm_Vertical
J15: Photo 5; PinHeader_1x01_P1.00mm_Vertical
J16: Photo 6; PinHeader_1x01_P1.00mm_Vertical
J17: LED 3-4; PinHeader_1x01_P1.00mm_Vertical
J18: LED 5-6; PinHeader_1x01_P1.00mm_Vertical
J19: LED 7-8; PinHeader_1x01_P1.00mm_Vertical
J20: LED 9-10; PinHeader_1x01_P1.00mm_Vertical
J21: LED 11-12; PinHeader_1x01_P1.00mm_Vertical
L1, L2: SHP0320P-F470NAP; SHP0320PF470NAP; Manufacturer_Part_Number SHP0320P-F470NAP
R1, R2, R3, R4, R5, R6, R7, R8, R9, R10, R11: R; R_0402_1005Metric_Pad0.72x0.64mm_HandSolder
U1: TPS73633DBV; SOT-23-5

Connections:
/CHARGE_SHUTDOWN: IC2.12 (32K_XP/IO32), IC3.1 (G), R7.2
/EN: IC2.9 (EN), J1.3
/IO25: IC1.15 (A0), IC2.14 (IO25)
/IO26: IC1.14 (A1), IC2.15 (IO26)
/IO27: IC1.13 (A2), IC2.16 (IO27)
/IO33: IC1.16 (EN), IC2.13 (32K_XN/IO33)
/PROG: IC2.23 (IO0), IC2.24 (IO4), J1.6
/RX: IC2.40 (U0RXD/IO3), J1.4
/TX: IC2.41 (U0TXD/IO1), J1.5
/VDD: C2.1, C4.1, C7.1, IC1.6 (D), IC1.11 (VDD), IC2.1 (VDDA_1), IC2.3 (VDDA3P3_1), IC2.4 (VDDA3P3_2), IC2.43 (VDDA_2), IC2.46 (VDDA_3), J1.2, U1.5 (OUT)
/V_IN: C5.1, IC5.3 (D), U1.1 (IN), U1.3 (EN)
GND: C1.2, C2.2, C3.2, C4.2, C5.2, C6.2, C7.2, C11.2, C12.1, D14.2 (A), IC1.12 (GND), IC2.49 (GND), IC3.2 (S), IC4.5 (GND_1), IC4.17 (GND_2), J1.1, J4.1, R1.1, R2.2, R3.2, R4.2, R5.2, R6.2, R7.1, R9.1, R11.1, U1.2 (GND)
unnamed: ANT1.1 (FEED), C1.1, L1.1
unnamed: C8.1, D13.2 (A), D14.1 (K)
unnamed: C11.1, D13.1 (K), D15.1 (K), IC4.3 (IN), IC4.16 (RUN), R8.2
unnamed: C9.1, D15.2 (A), IC4.6 (DHC)
unnamed: IC1.2 (S1), J6.1
unnamed: IC1.3 (S2), J17.1
unnamed: IC1.4 (S3), J18.1
unnamed: IC1.5 (S4), J19.1
unnamed: IC1.8 (S7), J21.1
unnamed: IC1.7 (S8), J20.1
unnamed: IC2.31 (CLK/IO6), J14.1, R4.1
unnamed: IC2.30 (CMD/IO11), J15.1, R5.1
unnamed: IC2.34 (IO5), J5.1, R1.2
unnamed: C3.1, IC2.2 (LNA_IN), L1.2
unnamed: IC2.32 (SD0/IO7), J13.1, R3.1
unnamed: IC2.33 (SD1/IO8), J12.1, R2.1
unnamed: IC2.29 (SD3/IO10), J16.1, R6.1
unnamed: C8.2, C9.2, IC3.3 (D)
unnamed: IC4.9 (BAT), IC4.10 (BATSNS), IC4.12 (NTC), IC5.2 (S), J3.1, R10.2, R11.2
unnamed: C10.2, IC4.2 (BOOST)
unnamed: IC4.8 (CHGSNS), L2.2
unnamed: C12.2, IC4.1 (INTVCC), IC4.7 (FREQ), R10.1
unnamed: IC4.13 (PROG), R9.2
unnamed: C10.1, IC4.4 (SW), L2.1
unnamed: IC4.14 (~CHRG), IC5.1 (G), R8.1
unnamed: C6.1, U1.4 (NR)

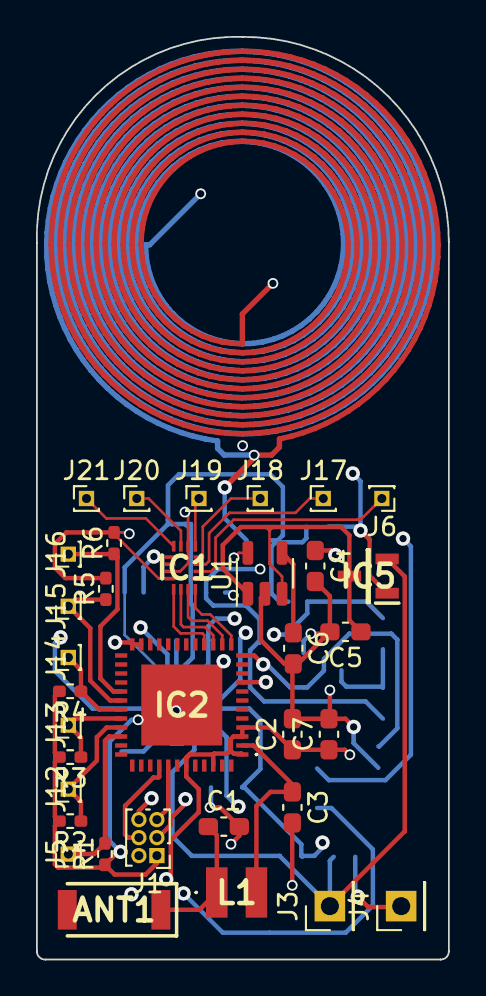
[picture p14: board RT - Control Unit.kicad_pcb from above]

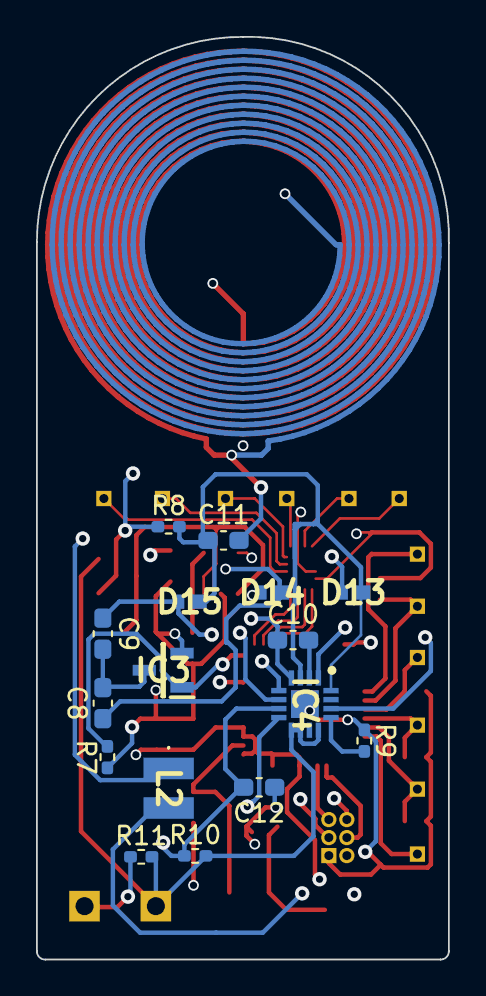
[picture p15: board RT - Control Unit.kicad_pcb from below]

Board: 4 copper layers, 22.9 x 51.3 mm, 50 parts (16 on the bottom side), 38 nets.

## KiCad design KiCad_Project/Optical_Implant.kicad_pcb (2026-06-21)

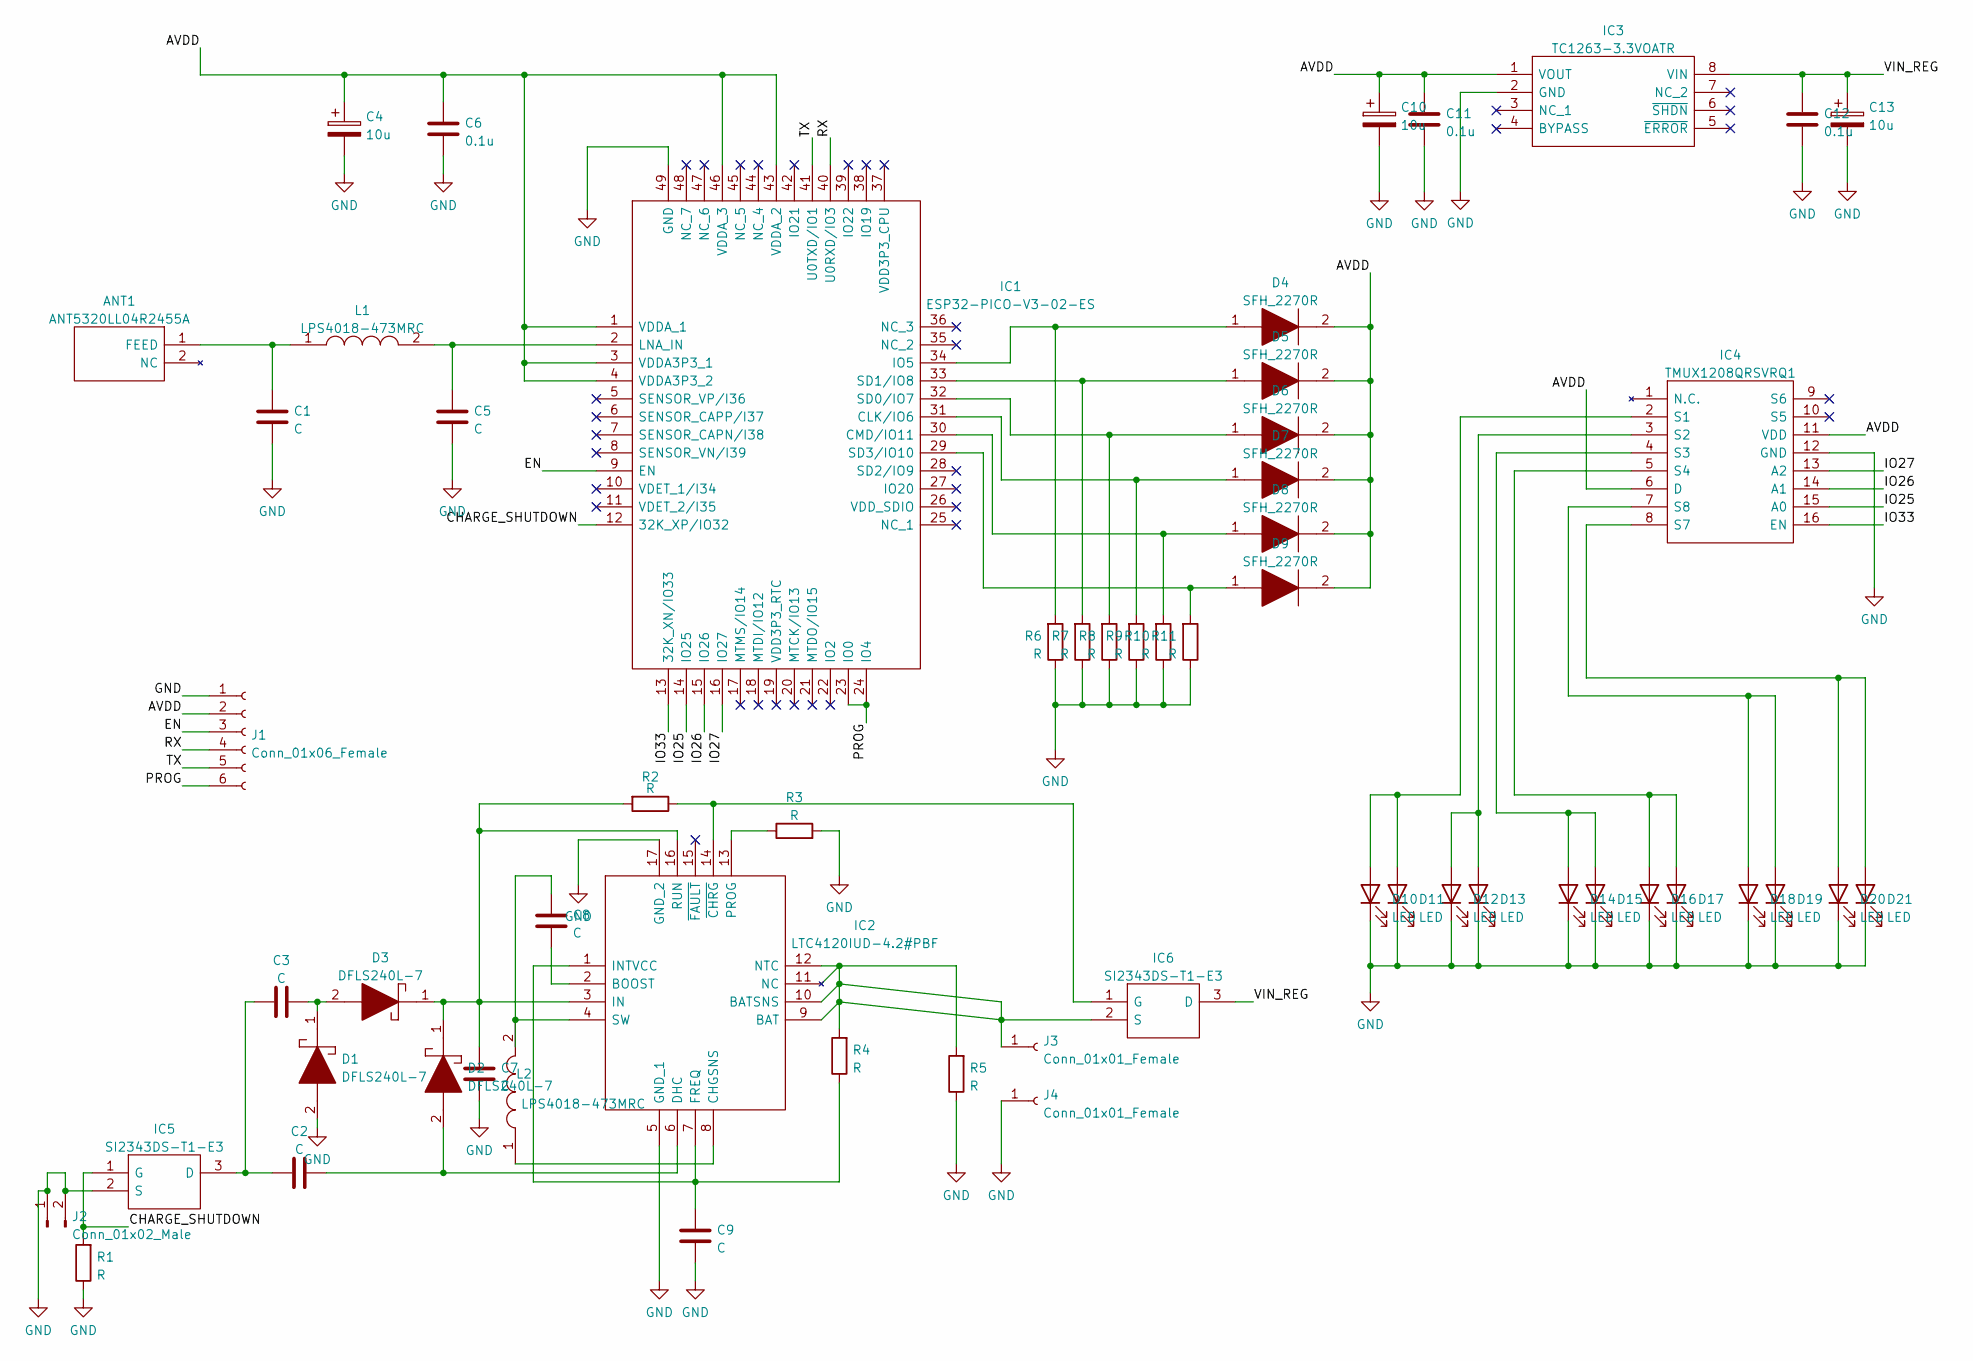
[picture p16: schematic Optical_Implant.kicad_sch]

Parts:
ANT1: ANT5320LL04R2455A; ANTC5320X170N; Mouser Part Number 603-ANT5320LL04R2455
C1, C2, C3, C5, C7, C8, C9: C; C_0603_1608Metric_Pad1.08x0.95mm_HandSolder
C4, C10, C13: 10u; C_0603_1608Metric_Pad1.08x0.95mm_HandSolder
C6, C11, C12: 0.1u; C_0603_1608Metric_Pad1.08x0.95mm_HandSolder
D1, D2, D3: DFLS240L-7; DFLS240L7; Manufacturer_Part_Number DFLS240L-7; Mouser Part Number 621-DFLS240L-7
D4, D5, D6, D7, D8, D9: SFH_2270R; SFH2270R; Mouser Part Number 720-SFH2270R
D10, D11, D12, D13, D14, D15, D16, D17, D18, D19, D20, D21: LED; LED_0603_1608Metric_Pad1.05x0.95mm_HandSolder
IC1: ESP32-PICO-V3-02-ES; ESP32PICOV302ES; Manufacturer_Part_Number ESP32-PICO-V3-02-ES
IC2: LTC4120IUD-4.2#PBF; QFN50P300X300X80-17N-D; Mouser Part Number 584-C4120IUD-4.2PBF
IC3: TC1263-3.3VOATR; SOIC127P600X175-8N; Mouser Part Number 579-TC1263-3.3VOATR
IC4: TMUX1208QRSVRQ1; Mouser Part Number 595-TMUX1208QRSVRQ1
IC5, IC6: SI2343DS-T1-E3; SOT95P237X112-3N; Mouser Part Number 781-SI2343DS-T1-E3
J1: Conn_01x06_Female; PinHeader_2x03_P1.00mm_Vertical
J2: Conn_01x02_Male; PinHeader_1x02_P2.54mm_Vertical
J3, J4: Conn_01x01_Female; PinHeader_1x01_P2.54mm_Vertical
L1: LPS4018-473MRC; L_0603_1608Metric_Pad1.05x0.95mm_HandSolder; Manufacturer_Part_Number LPS4018-473MRC; Mouser Part Number 994-LPS4018-473MRC
L2: LPS4018-473MRC; LPS4018473MRC; Manufacturer_Part_Number LPS4018-473MRC; Mouser Part Number 994-LPS4018-473MRC
R1, R2, R3, R4, R5, R6, R7, R8, R9, R10, R11: R; R_0402_1005Metric_Pad0.72x0.64mm_HandSolder

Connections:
/AVDD: C4.1, C6.1, C10.1, C11.1, D4.2, D5.2, D6.2, D7.2, D8.2, D9.2, IC1.1 (VDDA_1), IC1.3 (VDDA3P3_1), IC1.4 (VDDA3P3_2), IC1.43 (VDDA_2), IC1.46 (VDDA_3), IC3.1 (VOUT), IC4.6 (D), IC4.11 (VDD), J1.2
/CHARGE_SHUTDOWN: IC1.12 (32K_XP/IO32), IC5.1 (G), R1.2
/EN: IC1.9 (EN), J1.3
/IO25: IC1.14 (IO25), IC4.15 (A0)
/IO26: IC1.15 (IO26), IC4.14 (A1)
/IO27: IC1.16 (IO27), IC4.13 (A2)
/IO33: IC1.13 (32K_XN/IO33), IC4.16 (EN)
/PROG: IC1.23 (IO0), IC1.24 (IO4), J1.6
/RX: IC1.40 (U0RXD/IO3), J1.4
/TX: IC1.41 (U0TXD/IO1), J1.5
/VIN_REG: C12.1, C13.1, IC3.8 (VIN), IC6.3 (D)
GND: C1.2, C4.2, C5.2, C6.2, C7.2, C9.2, C10.2, C11.2, C12.2, C13.2, D1.2, D10.1 (K), D11.1 (K), D12.1 (K), D13.1 (K), D14.1 (K), D15.1 (K), D16.1 (K), D17.1 (K), D18.1 (K), D19.1 (K), D20.1 (K), D21.1 (K), IC1.49 (GND), IC2.5 (GND_1), IC2.17 (GND_2), IC3.2 (GND), IC4.12 (GND), IC5.2 (S), J1.1, J2.1, J2.2, J4.1, R1.1, R3.2, R5.1, R6.1, R7.1, R8.1, R9.1, R10.1, R11.1
unnamed: ANT1.1 (FEED), C1.1, L1.1
unnamed: C2.1, C3.1, IC5.3 (D)
unnamed: C2.2, D2.2, IC2.6 (DHC)
unnamed: C3.2, D1.1, D3.2
unnamed: C5.1, IC1.2 (LNA_IN), L1.2
unnamed: C7.1, D2.1, D3.1, IC2.3 (IN), IC2.16 (RUN), R2.2
unnamed: C8.1, IC2.4 (SW), L2.2
unnamed: C8.2, IC2.2 (BOOST)
unnamed: C9.1, IC2.1 (INTVCC), IC2.7 (FREQ), R4.1
unnamed: D4.1, IC1.34 (IO5), R6.2
unnamed: D5.1, IC1.33 (SD1/IO8), R7.2
unnamed: D6.1, IC1.32 (SD0/IO7), R8.2
unnamed: D7.1, IC1.31 (CLK/IO6), R9.2
unnamed: D8.1, IC1.30 (CMD/IO11), R10.2
unnamed: D9.1, IC1.29 (SD3/IO10), R11.2
unnamed: D10.2 (A), D11.2 (A), IC4.2 (S1)
unnamed: D12.2 (A), D13.2 (A), IC4.3 (S2)
unnamed: D14.2 (A), D15.2 (A), IC4.4 (S3)
unnamed: D16.2 (A), D17.2 (A), IC4.5 (S4)
unnamed: D18.2 (A), D19.2 (A), IC4.7 (S8)
unnamed: D20.2 (A), D21.2 (A), IC4.8 (S7)
unnamed: IC2.8 (CHGSNS), L2.1
unnamed: IC2.13 (PROG), R3.1
unnamed: IC2.14 (~CHRG), IC6.1 (G), R2.1

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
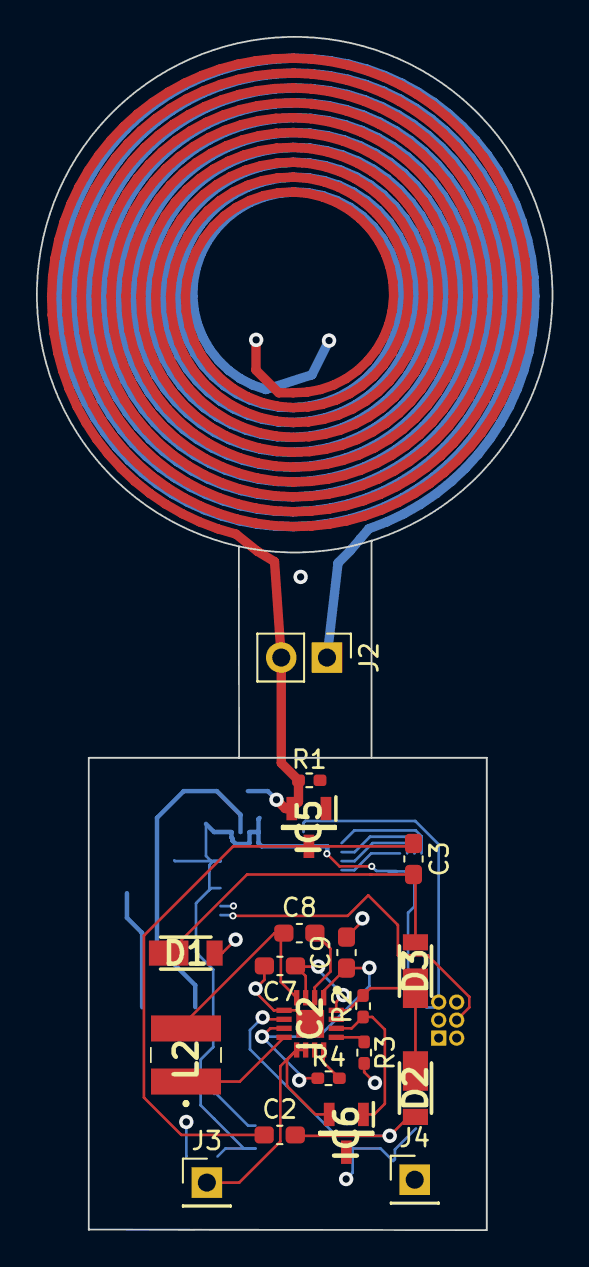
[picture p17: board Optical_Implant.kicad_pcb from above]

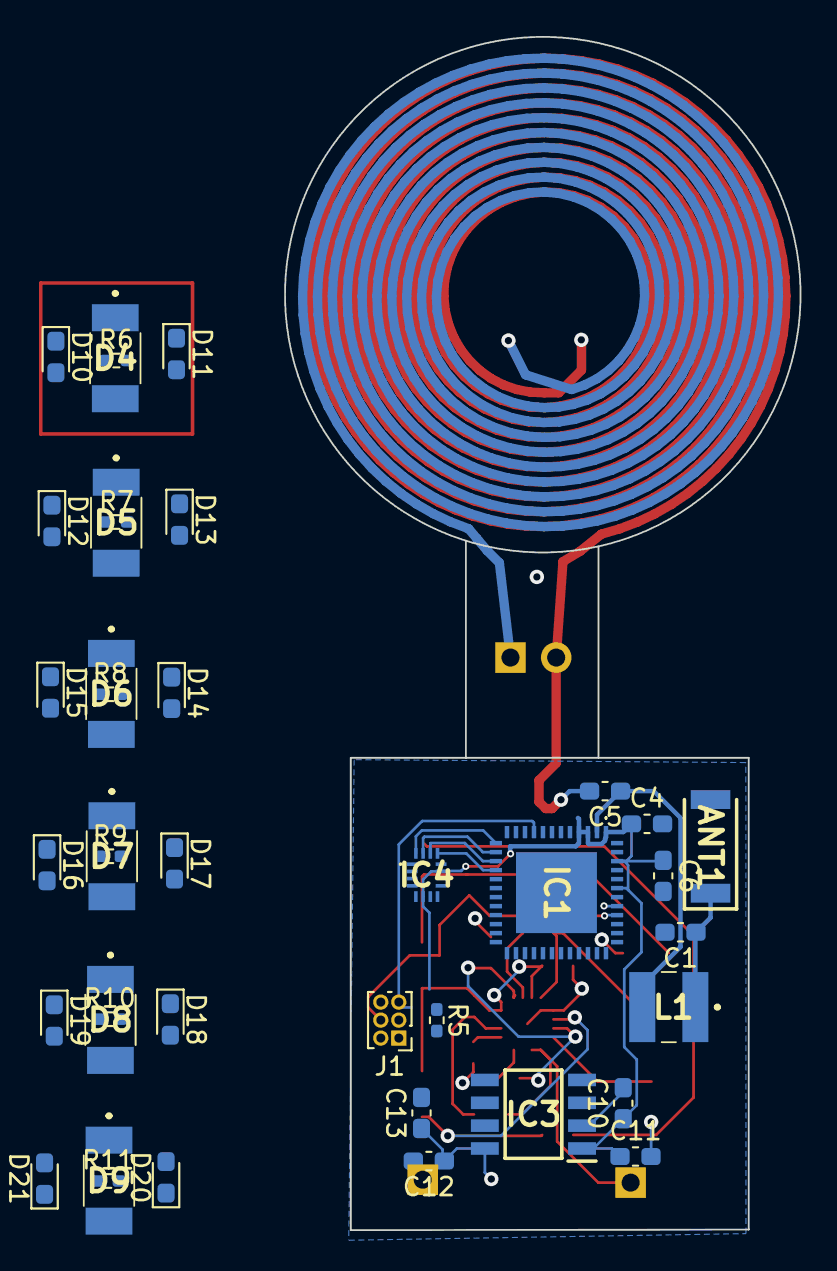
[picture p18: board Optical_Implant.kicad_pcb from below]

Board: 4 copper layers, 28.6 x 66.3 mm, 58 parts (39 on the bottom side), 38 nets.
